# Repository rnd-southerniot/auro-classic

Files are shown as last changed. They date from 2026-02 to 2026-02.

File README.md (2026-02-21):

# Airborne Classic (Aurbotstem Academy)

XRP-style robot car firmware stack for STEM learning, currently focused on USB serial bring-up and deterministic RP2040 control.

## Current Status (February 21, 2026)
- Gate P1-0: PASS (MicroPython deploy, boot telemetry, `ping` ack, DISARMED-by-default).
- Gate P1-1: PASS (IRQ encoder counting validated with wheel-direction tests).
- PicoSDK track: active and validated (build/flash/smoke PASS, PIO encoder telemetry integrated).

## Repository Layout
- `firmware_mpy/`: MicroPython firmware (`main.py`, `lib/hw.py`, `config.json`).
- `firmware_sdk/`: PicoSDK firmware with NDJSON loop and PIO encoder sampler.
- `protocol/`: NDJSON protocol spec + JSON schema.
- `tools/`: host utilities (`mpy_sync.sh`, CAD bbox extraction).
- `cad/`: chassis/wheel 3MF artifacts and extracted metadata.
- `docs/`: phase status and project notes.
- `skills/`: reusable Codex skills for this repo.
- `MEMORY.md`: persistent decisions and validated environment facts.

## Quick Start: MicroPython Path
```bash
python3 -m pip install --upgrade mpremote
./tools/mpy_sync.sh
```
Expected behavior: boot telemetry in `DISARMED` mode, then `{"type":"ack","id":"1","ok":true}` for `ping`.

## Quick Start: PicoSDK Path
Install local dependencies (one-time):
```bash
git clone --depth 1 https://github.com/raspberrypi/pico-sdk.git third_party/pico-sdk
git -C third_party/pico-sdk submodule update --init --recursive
curl -fL -o /tmp/arm-gnu-toolchain.tar.xz https://developer.arm.com/-/media/Files/downloads/gnu/15.2.rel1/binrel/arm-gnu-toolchain-15.2.rel1-darwin-arm64-arm-none-eabi.tar.xz
tar -xf /tmp/arm-gnu-toolchain.tar.xz -C third_party
```

Then build:
```bash
export PICO_SDK_PATH="$PWD/third_party/pico-sdk"
export PICO_TOOLCHAIN_PATH="$PWD/third_party/arm-gnu-toolchain-15.2.rel1-darwin-arm64-arm-none-eabi/bin"
cmake -S firmware_sdk -B firmware_sdk/build-pico-arm -G Ninja
cmake --build firmware_sdk/build-pico-arm -j
```
Flash UF2: copy `firmware_sdk/build-pico-arm/airborne_classic_fw.uf2` to `RPI-RP2`.

## Source of Truth
- Hardware: `HARDWARE_MAP.md`
- Serial protocol: `protocol/ndjson_v1.md`
- Latest phase evidence: `docs/PHASE1_STATUS.md`

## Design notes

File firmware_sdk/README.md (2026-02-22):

# firmware_sdk

PicoSDK production firmware for Airborne Classic.

## Scope
Current implementation provides:
- USB NDJSON command/telemetry loop in `src/main.c`
- PIO-based quadrature sampling (`src/quadrature_sample.pio`)
- encoder count telemetry fields (`enc_l`, `enc_r`)

## Prerequisites
- Pico SDK checkout
- Arm GNU toolchain with `arm-none-eabi-*`
- CMake + Ninja

Tested local setup:
- `PICO_SDK_PATH=$PWD/third_party/pico-sdk`
- `PICO_TOOLCHAIN_PATH=$PWD/third_party/arm-gnu-toolchain-15.2.rel1-darwin-arm64-arm-none-eabi/bin`

## Install Local Dependencies (one-time)
```bash
git clone --depth 1 https://github.com/raspberrypi/pico-sdk.git third_party/pico-sdk
git -C third_party/pico-sdk submodule update --init --recursive
curl -fL -o /tmp/arm-gnu-toolchain.tar.xz https://developer.arm.com/-/media/Files/downloads/gnu/15.2.rel1/binrel/arm-gnu-toolchain-15.2.rel1-darwin-arm64-arm-none-eabi.tar.xz
tar -xf /tmp/arm-gnu-toolchain.tar.xz -C third_party
```

## Build
```bash
cmake -S firmware_sdk -B firmware_sdk/build-pico-arm -G Ninja
cmake --build firmware_sdk/build-pico-arm -j
```

## Flash
1. Reboot to BOOTSEL (`picotool reboot -u -f`) or hold BOOTSEL while plugging USB.
2. Copy `firmware_sdk/build-pico-arm/airborne_classic_fw.uf2` to `RPI-RP2`.

## Protocol Coverage
Implemented command subset:
- `ping`, `version`, `arm`, `disarm`, `set_pwm`, `set_rpm`, `cal_encoders`, `cal_imu`, `stop`

`set_rpm` currently maps target RPM values to open-loop PWM using `OPEN_LOOP_MAX_ABS_RPM` in `src/main.c`.
`cal_encoders` resets encoder counts and RPM integrators; `cal_imu` currently returns a noop ack.

Telemetry:
- `mode`, `armed`, `pwm_l`, `pwm_r`, `enc_l`, `enc_r`, `rpm_l`, `rpm_r`, `yaw`, `fault`
- `rpm_*` is estimated from encoder deltas each telemetry interval.
- `COUNTS_PER_WHEEL_REV_L/R` in `src/main.c` are currently calibrated to `582/583` from Feb 22, 2026 bench trials.

## Notes
- Pin mapping remains anchored in `HARDWARE_MAP.md`.
- Protocol compatibility target remains `protocol/ndjson_v1.md`.
- Encoder sign is normalized in telemetry using `ENC_L_SIGN` / `ENC_R_SIGN` in `src/main.c`.

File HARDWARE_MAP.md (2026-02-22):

# Airborne Classic — HARDWARE_MAP (source of truth)

## Chassis / kinematics (LOCKED TO PRINTED CAD)

Source: 3MF CAD files in `cad/`.

- Wheel diameter (CAD bbox): **~54.875 mm** (treat as 55 mm)
- Wheel thickness (CAD bbox): **~9.125 mm**
- Track width (CAD assembly, wheel-center to wheel-center): **~155.0 mm** *(computed)*
- Wheelbase (measured): **62 mm** (drive axle center → caster contact center)

> Current CAD-derived frame overall extents (PCA-aligned bbox):
> - Length/width extents (two largest): ~223.78 mm and ~222.30 mm
> - Height extent (smallest): ~38.50 mm
>
> TODO (still needs extraction of axle center positions):
> - Track width (wheel-center to wheel-center)
> - Wheelbase (axle-center to axle-center)
> - Encoder mounting geometry

## Controller: Cytron Maker Pi RP2040 (Pico)

### Motor driver pins (locked)
- M1A = GP8
- M1B = GP9
- M2A = GP10
- M2B = GP11

Truth table:
- 00 brake
- 10 forward
- 01 backward
- 11 coast (Hi-Z)

PWM frequency target: ~20 kHz

### Onboard peripherals
- WS2812 RGB: GP18
- Buttons: GP20, GP21
- Buzzer: GP22
- Servo signals: GP12–GP15

## Encoders (quadrature, locked approach)

### Pin assignment (chosen)
- Left: ENC_L_A = GP2, ENC_L_B = GP3
- Right: ENC_R_A = GP4, ENC_R_B = GP5

### Decoder strategy
- MicroPython bring-up: IRQ-based counting (low speed)
- PicoSDK production: PIO-based sampling + CPU transition decode
- Telemetry sign convention: forward normalized positive on both channels (`ENC_L_SIGN=1`, `ENC_R_SIGN=-1`)

### Calibration
- counts-per-wheel-rev (measured February 22, 2026; 3 manual 1-rev trials each):
  - left trials: 576, 586, 585 -> average 582.33 -> use **582**
  - right trials: 575, 591, 584 -> average 583.33 -> use **583**
- wheel diameter: locked to CAD (~55 mm)

## IMU: ICM-20948

### Bus (chosen)
- I2C1: SDA=GP6, SCL=GP7

> TODO: confirm ICM-20948 I2C address on your breakout and whether AD0 is strapped.

## Power
- TBD (battery type/voltage for car)

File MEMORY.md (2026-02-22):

# Project Memory

## Stable Decisions
- Use gate-based development with stop-on-FAIL and transcript evidence.
- Treat `HARDWARE_MAP.md` as hardware source of truth.
- Treat `protocol/ndjson_v1.md` as wire contract; staged subset implementation is allowed by gate.

## Validated Hardware/Firmware Facts
- Board: Cytron Maker Pi RP2040.
- Encoder pins: left GP2/GP3, right GP4/GP5.
- Motor pins: GP8-GP11.
- I2C bus for IMU mapping: `I2C1` on GP6/GP7.
- MicroPython runtime requires stdout flush guard (`sys.stdout.flush` may be absent).

## Validated Build/Flash Facts
- PicoSDK build works with local vendored toolchain + SDK under `third_party/`.
- Working build output path: `firmware_sdk/build-pico-arm/airborne_classic_fw.uf2`.
- Reliable BOOTSEL command flow:
  - `picotool reboot -u -f`
  - copy UF2 to `RPI-RP2`.

## Encoder Sign Convention
- Telemetry is normalized so forward is positive for both channels.
- Configured in `firmware_sdk/src/main.c` with:
  - `ENC_L_SIGN = 1`
  - `ENC_R_SIGN = -1`

## Encoder Calibration Baseline
- Date: February 22, 2026.
- Left counts/rev trials: 576, 586, 585 -> average 582.33 -> configured 582.
- Right counts/rev trials: 575, 591, 584 -> average 583.33 -> configured 583.

## Current Priorities
1. Replace open-loop `set_rpm` mapping with closed-loop RPM control.
2. Replace `cal_imu` noop with hardware-backed IMU calibration flow.
3. Add persistent calibration command flow to write/read runtime calibration values.

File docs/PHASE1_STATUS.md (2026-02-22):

# Phase 1 Status (As of February 22, 2026)

## Gate Results
- P1-0: PASS
- P1-1: PASS
- PicoSDK smoke gate: PASS

## Verified Behaviors
- MicroPython path:
  - deploy via `./tools/mpy_sync.sh`
  - boot telemetry in `DISARMED`
  - `ping` ack success
  - encoder IRQ counting with direction-dependent deltas
- PicoSDK path:
  - deterministic build with local SDK/toolchain
  - UF2 flash to RP2040
  - NDJSON command loop acks for `ping/version/arm/disarm/set_pwm/set_rpm/cal_encoders/cal_imu/stop`
  - PIO-derived encoder telemetry (`enc_l`, `enc_r`)

## Build Environment Used
- `PICO_SDK_PATH=/Users/robotics/airborne-classic/third_party/pico-sdk`
- `PICO_TOOLCHAIN_PATH=/Users/robotics/airborne-classic/third_party/arm-gnu-toolchain-15.2.rel1-darwin-arm64-arm-none-eabi/bin`
- Board serial: `/dev/cu.usbmodem211301`

## Known Gaps
- IMU calibration is currently a protocol-compatible noop ack (sensor calibration flow not implemented).
- Closed-loop RPM control is not implemented yet (`set_rpm` is open-loop mapping).

## Calibration Snapshot (February 22, 2026)
- Left wheel counts/rev trials: `576`, `586`, `585` -> average `582.33` -> configured `582`.
- Right wheel counts/rev trials: `575`, `591`, `584` -> average `583.33` -> configured `583`.

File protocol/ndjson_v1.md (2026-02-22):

# NDJSON Serial Protocol v1 (Airborne Classic)

Transport: USB CDC serial
Encoding: newline-delimited JSON (one JSON object per line)

## Commands (Hub → Controller)

All commands include:
- `type: "cmd"`
- `id`: string UUID
- `ts`: epoch milliseconds
- `cmd`: command name

### Arm/disarm
```json
{"type":"cmd","id":"uuid","ts":0,"cmd":"arm"}
{"type":"cmd","id":"uuid","ts":0,"cmd":"disarm"}
```

### Motor control
Open loop PWM (normalized -1..1):
```json
{"type":"cmd","id":"uuid","ts":0,"cmd":"set_pwm","left":0.2,"right":0.2}
```

RPM command:
```json
{"type":"cmd","id":"uuid","ts":0,"cmd":"set_rpm","left":120,"right":120}
```
Current firmware subsets map RPM targets to open-loop PWM; closed-loop control is a later phase.

Emergency stop:
```json
{"type":"cmd","id":"uuid","ts":0,"cmd":"stop"}
```

### Calibration
```json
{"type":"cmd","id":"uuid","ts":0,"cmd":"cal_imu"}
{"type":"cmd","id":"uuid","ts":0,"cmd":"cal_encoders"}
```

### Introspection
```json
{"type":"cmd","id":"uuid","ts":0,"cmd":"ping"}
{"type":"cmd","id":"uuid","ts":0,"cmd":"i2c_scan"}
{"type":"cmd","id":"uuid","ts":0,"cmd":"version"}
```

### Logging
Default is **NDJSON only**. Human logs can be enabled for debugging.

```json
{"type":"cmd","id":"uuid","ts":0,"cmd":"set_log","on":true}
{"type":"cmd","id":"uuid","ts":0,"cmd":"set_log","on":false}
```

Human log lines are prefixed with `# ` so parsers can ignore them.

## Telemetry (Controller → Hub)

Telemetry at 10–50 Hz depending mode.

```json
{
  "type":"tele",
  "ts":0,
  "mode":"DISARMED|ARMED|TELEOP|AUTO|FAULT",
  "armed":false,
  "pwm_l":0.0,
  "pwm_r":0.0,
  "enc_l":0,
  "enc_r":0,
  "rpm_l":0.0,
  "rpm_r":0.0,
  "yaw":0.0,
  "fault":null
}
```

## Acks (Controller → Hub)

```json
{"type":"ack","id":"uuid","ok":true}
```

Error:
```json
{"type":"ack","id":"uuid","ok":false,"error":{"code":"bad_cmd","message":"..."}}
```

## Implementation Status (February 22, 2026)

Protocol v1 is the contract; firmware tracks it in staged subsets.

- MicroPython (`firmware_mpy/main.py`) currently implements:
  - `ping`, `set_log`, `version`, `i2c_scan`, `arm`, `disarm`, `stop`, `set_pwm`, `set_rpm` (open-loop mapping), `cal_encoders`, `cal_imu` (noop ack)
- PicoSDK (`firmware_sdk/src/main.c`) currently implements:
  - `ping`, `version`, `arm`, `disarm`, `stop`, `set_pwm`, `set_rpm` (open-loop mapping), `cal_encoders`, `cal_imu` (noop ack)
- Deferred in both tracks (planned later gates):
  - hardware-backed IMU calibration flow

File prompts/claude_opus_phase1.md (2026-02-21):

# Claude Opus — Airborne Classic (Phase 1) Master Prompt

Use this prompt with Claude Opus (4.x). If your tooling asks for a model name, use your provider's Opus alias.

## Role
You are a senior robotics+curriculum engineer. Produce a gate-based plan and code changes for Phase 1 (USB-only):
- MicroPython auto-run bring-up
- PicoSDK production firmware (PIO encoders)
- local-only learning hub for a teacher Mac

## Inputs
- Hardware map: `HARDWARE_MAP.md`
- NDJSON protocol: `protocol/ndjson_v1.md`
- Maker Pi RP2040 motor pins: GP8–GP11 (truth table)
- Encoders: quadrature A/B
- IMU: ICM-20948 via I2C
- Kinematics locked to printed CAD:
  - wheel dia ~55mm
  - track width ~155mm
  - wheelbase 62mm

## Output requirements
1) Provide Gate P1-0..P1-3 checklists.
2) For each gate, list tests and expected logs.
3) Provide minimal code diffs for the MicroPython skeleton first.
4) Do not start PicoSDK until MP gates pass.
5) Provide a student-facing mini-lab outline for Gate P1-2 and P1-3.

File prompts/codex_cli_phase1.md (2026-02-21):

# Codex CLI — Airborne Classic (Phase 1) Master Prompt

Paste into codex CLI.

## Mission
Build Phase 1 (USB-only) for **Airborne Classic**: MicroPython bring-up track (auto-run) + PicoSDK production track (PIO encoders) + local-only teacher learning hub.

## Non-negotiables
- Gate-based development. Stop on FAIL.
- Source-of-truth hardware in `HARDWARE_MAP.md`.
- NDJSON protocol v1 in `protocol/ndjson_v1.md`.

## Repository
Root: `airborne-classic/`

## Gate P1-0 (deliver now)
1) Confirm `HARDWARE_MAP.md` exists and is consistent.
2) Implement MicroPython auto-run skeleton:
   - `firmware_mpy/main.py`
   - `firmware_mpy/lib/hw.py`
   - `firmware_mpy/config.json`
   - `tools/mpy_sync.sh`
3) Provide a tiny verification transcript:
   - `mpy_sync.sh`
   - `echo '{"type":"cmd","id":"1","ts":0,"cmd":"ping"}' | <serial>` (or via mpremote repl)

## Gate P1-1 (next)
- Expand MicroPython to include encoder IRQ counting for slow speed.

## PicoSDK track (do not start until MP gates pass)
- Create `firmware_sdk/` skeleton with:
  - quadrature PIO plan
  - build instructions

## Output format
- Print PASS/FAIL for Gate P1-0 with evidence.
- If FAIL, provide debug checklist.

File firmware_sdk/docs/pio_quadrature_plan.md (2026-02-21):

# Quadrature PIO Plan

## Goal
Implement deterministic encoder counting on RP2040 PIO for Airborne Classic production firmware.

## Hardware Inputs
From `HARDWARE_MAP.md`:
- Left encoder: `ENC_L_A=GP2`, `ENC_L_B=GP3`
- Right encoder: `ENC_R_A=GP4`, `ENC_R_B=GP5`

## Architecture
- Use one PIO state machine per wheel encoder.
- Each state machine samples A/B, tracks 2-bit state transitions, and emits signed step deltas.
- Core loop aggregates deltas into 32-bit counts (`enc_l`, `enc_r`).

## Data Path
1. PIO captures edge transitions with fixed timing.
2. IRQ or FIFO polling transfers deltas to CPU.
3. Control task updates counts and computes low-rate RPM.
4. Telemetry publishes NDJSON-compatible fields (`enc_l`, `enc_r`, `rpm_l`, `rpm_r`).

## Failure Handling
- Invalid transitions (`00->11`, `01->10`) are counted as noise events.
- FIFO overflow increments an overflow counter and raises a soft fault.
- Encoder disconnect detection: no transitions for a configurable timeout while PWM is non-zero.

## Milestones
1. PIO state machine stub compiles and streams raw A/B states.
2. Signed delta decoding validated against hand rotation.
3. Count accumulation + overflow counters integrated.
4. Telemetry export aligned with `protocol/ndjson_v1.md`.

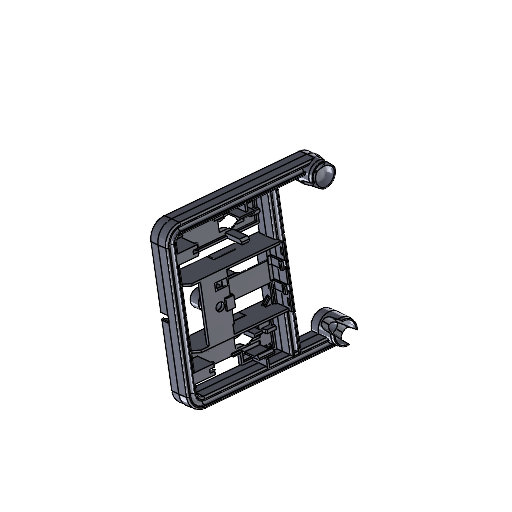
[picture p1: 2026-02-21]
cad/extracted/frame/Metadata/thumbnail.png

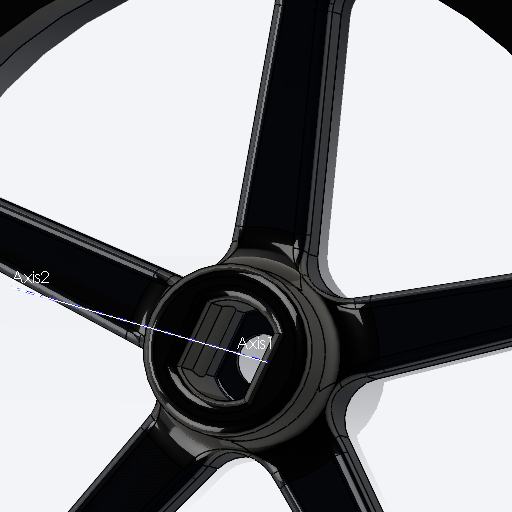
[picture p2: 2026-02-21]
cad/extracted/wheel/Metadata/thumbnail.png

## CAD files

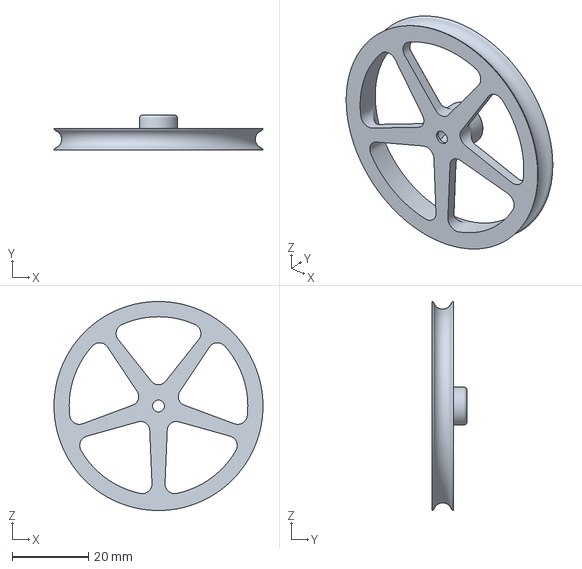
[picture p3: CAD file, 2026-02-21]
cad/wheel-fixed-bore.3mf
54.9 x 9.13 x 54.9 mm

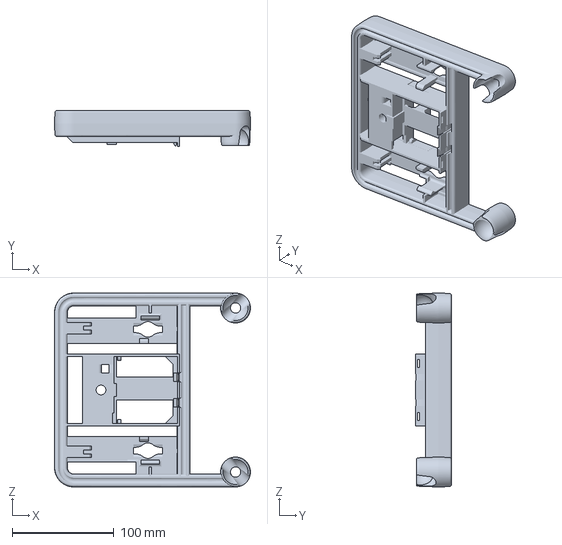
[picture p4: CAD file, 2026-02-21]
cad/single-part-frame-v13.3mf
192.5 x 35.2 x 190.5 mm

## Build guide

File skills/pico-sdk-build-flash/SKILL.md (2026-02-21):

---
name: pico-sdk-build-flash
description: Build, flash, and smoke-test Airborne Classic PicoSDK firmware on RP2040 using reproducible local paths and UF2 workflows. Use when configuring toolchain paths, running CMake/Ninja builds, rebooting to BOOTSEL, copying UF2 images, and verifying NDJSON telemetry/ack behavior after flash.
---

# Pico SDK Build Flash

## Use Deterministic Build Paths
1. Prefer repository-local toolchain and SDK paths from `references/build-paths.md`.
2. Configure with Ninja and an explicit build directory (`firmware_sdk/build-pico-arm`).
3. Re-run configure when CMake cache uses a different generator.

## Build Then Flash
1. Run `scripts/build_sdk.sh` first.
2. Run `scripts/flash_uf2.sh` with the UF2 path.
3. If copy fails on first attempt, retry once after mount confirms writable BOOTSEL volume.

## Smoke-Test Immediately
- Send `ping` and `version` commands and verify acks.
- Confirm telemetry stream appears without parse errors.
- Check encoder fields are present (`enc_l`, `enc_r`).

## Resources
- `references/build-paths.md`: canonical env/path values and fallback notes.
- `scripts/build_sdk.sh`: deterministic build wrapper.
- `scripts/flash_uf2.sh`: BOOTSEL flash helper.

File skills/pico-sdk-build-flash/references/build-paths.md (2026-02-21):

# Build Paths

## Preferred Local Paths
- `PICO_SDK_PATH=$REPO/third_party/pico-sdk`
- `PICO_TOOLCHAIN_PATH=$REPO/third_party/arm-gnu-toolchain-15.2.rel1-darwin-arm64-arm-none-eabi/bin`

## Configure + Build
```bash
PICO_SDK_PATH="$PWD/third_party/pico-sdk" \
PICO_TOOLCHAIN_PATH="$PWD/third_party/arm-gnu-toolchain-15.2.rel1-darwin-arm64-arm-none-eabi/bin" \
cmake -S firmware_sdk -B firmware_sdk/build-pico-arm -G Ninja

PICO_SDK_PATH="$PWD/third_party/pico-sdk" \
PICO_TOOLCHAIN_PATH="$PWD/third_party/arm-gnu-toolchain-15.2.rel1-darwin-arm64-arm-none-eabi/bin" \
cmake --build firmware_sdk/build-pico-arm -j
```

## Flash
- Reboot to BOOTSEL: `picotool reboot -u -f`
- Copy UF2 to `RPI-RP2`.

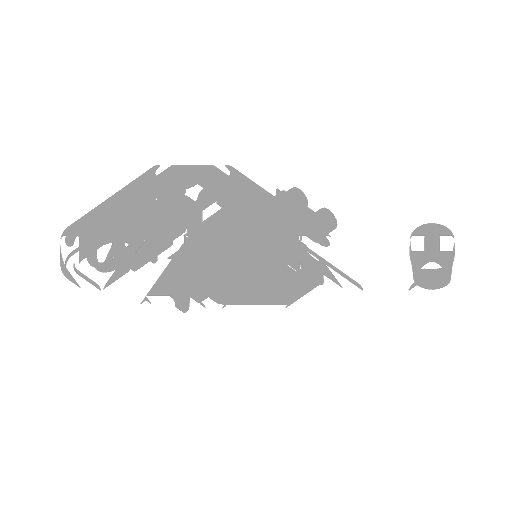
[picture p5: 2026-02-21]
cad/assembly2/extracted/Metadata/plate_no_light_1.png

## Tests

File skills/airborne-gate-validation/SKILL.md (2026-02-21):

---
name: airborne-gate-validation
description: Run gate-based validation for Airborne Classic RP2040 firmware with stop-on-fail behavior and transcript evidence. Use when verifying MicroPython or PicoSDK firmware gates, capturing serial ack/telemetry output, checking disarm/arm safety flow, validating encoder direction deltas, or preparing PASS/FAIL gate reports.
---

# Airborne Gate Validation

## Execute Gate Workflow
1. Load the checklist in `references/gate-checklist.md` and select the target track (`firmware_mpy` or `firmware_sdk`).
2. Start with non-motion checks first: boot telemetry, `ping`, `version`, and disarm safety.
3. Stop immediately on first failure and produce a focused debug checklist.
4. Only continue motion-based checks after non-motion checks pass.

## Capture Evidence
- Use `scripts/serial_capture.py` to collect line-by-line serial evidence.
- Always include:
  - commands sent,
  - ack lines,
  - at least one telemetry sample around each command.
- For encoder checks, report `delta_l` and `delta_r` over a fixed window.

## Report Format
- Print one gate status line: `Gate <name>: PASS|FAIL`.
- If PASS: include key evidence snippets and next gate recommendation.
- If FAIL: include exact failing step, raw error line, and immediate debug actions.

## Resources
- `references/gate-checklist.md`: execution order and acceptance criteria.
- `scripts/serial_capture.py`: repeatable capture utility for NDJSON sessions.

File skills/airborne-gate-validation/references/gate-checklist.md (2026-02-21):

# Gate Checklist

## Preflight
- Confirm board serial device (for example `/dev/cu.usbmodem211301`).
- Confirm firmware image to validate (`firmware_mpy` or `firmware_sdk`).
- Keep robot disarmed unless a test step explicitly requires `arm`.

## Baseline Checks
1. Boot telemetry appears and includes `mode` + `armed`.
2. `ping` command returns `{"type":"ack","ok":true}`.
3. `version` returns firmware identity.
4. Safety sequence (`disarm -> arm -> stop -> disarm`) returns all acks.

## Encoder Checks
1. Idle window: counts stable.
2. Left forward/backward windows: sign flips, right channel remains stable.
3. Right forward/backward windows: sign flips, left channel remains stable.
4. Document observed sign convention and whether normalization is applied.

## Failure Handling
- Stop on first failure.
- Capture raw line showing the failure.
- Suggest only the minimal corrective action before retry.

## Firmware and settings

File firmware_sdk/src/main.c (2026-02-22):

#include <stdbool.h>
#include <stdint.h>
#include <stdio.h>
#include <stdlib.h>
#include <string.h>
#include <math.h>

#include "hardware/gpio.h"
#include "hardware/pio.h"
#include "hardware/pwm.h"
#include "pico/stdlib.h"
#include "quadrature_sample.pio.h"

#define LINE_BUF_SIZE 256
#define ENC_L_PIN_BASE 2u
#define ENC_R_PIN_BASE 4u
#define ENCODER_SAMPLE_HZ 2000.0f
#define MOTOR_L_A_PIN 8u
#define MOTOR_L_B_PIN 9u
#define MOTOR_R_A_PIN 10u
#define MOTOR_R_B_PIN 11u
#define MOTOR_PWM_HZ 20000u
#define MOTOR_PWM_WRAP 6249u
#define ENC_L_SIGN 1
#define ENC_R_SIGN -1
// Calibrated from three 1-rev hand-turn trials (Feb 22, 2026):
// left: 576, 586, 585 -> 582.33 ; right: 575, 591, 584 -> 583.33
#define COUNTS_PER_WHEEL_REV_L 582.0f
#define COUNTS_PER_WHEEL_REV_R 583.0f
// Open-loop RPM command range mapped to PWM [-1, 1].
#define OPEN_LOOP_MAX_ABS_RPM 200.0f

typedef struct {
    bool armed;
    float pwm_l;
    float pwm_r;
    int32_t enc_l;
    int32_t enc_r;
    float rpm_l;
    float rpm_r;
} robot_state_t;

typedef struct {
    PIO pio;
    uint sm;
    uint pin_base;
    uint8_t prev_state;
    int32_t count;
} encoder_reader_t;

static uint32_t now_ms(void) {
    return to_ms_since_boot(get_absolute_time());
}

static void emit_tele(const robot_state_t *s) {
    printf(
        "{\"type\":\"tele\",\"ts\":%lu,\"mode\":\"%s\",\"armed\":%s,"
        "\"pwm_l\":%.3f,\"pwm_r\":%.3f,\"enc_l\":%ld,\"enc_r\":%ld,"
        "\"rpm_l\":%.3f,\"rpm_r\":%.3f,\"yaw\":0.0,\"fault\":null}\n",
        (unsigned long)now_ms(),
        s->armed ? "ARMED" : "DISARMED",
        s->armed ? "true" : "false",
        s->pwm_l,
        s->pwm_r,
        (long)s->enc_l,
        (long)s->enc_r,
        s->rpm_l,
        s->rpm_r
    );
}

static void emit_ack_ok(const char *id, const char *data_json_or_null) {
    if (data_json_or_null) {
        printf("{\"type\":\"ack\",\"id\":\"%s\",\"ok\":true,\"data\":%s}\n", id, data_json_or_null);
    } else {
        printf("{\"type\":\"ack\",\"id\":\"%s\",\"ok\":true}\n", id);
    }
}

static void emit_ack_err(const char *id, const char *code, const char *message) {
    printf(
        "{\"type\":\"ack\",\"id\":\"%s\",\"ok\":false,"
        "\"error\":{\"code\":\"%s\",\"message\":\"%s\"}}\n",
        id,
        code,
        message
    );
}

static bool extract_string_field(const char *line, const char *field, char *out, size_t out_size) {
    const char *p = strstr(line, field);
    const char *start;
    const char *end;
    size_t n;

    if (!p || out_size == 0) {
        return false;
    }
    p = strchr(p, ':');
    if (!p) {
        return false;
    }
    start = strchr(p, '"');
    if (!start) {
        return false;
    }
    start++;
    end = strchr(start, '"');
    if (!end) {
        return false;
    }
    n = (size_t)(end - start);
    if (n >= out_size) {
        n = out_size - 1;
    }
    memcpy(out, start, n);
    out[n] = '\0';
    return true;
}

static bool extract_number_field(const char *line, const char *field, float *value_out) {
    const char *p = strstr(line, field);
    char *endptr;
    float v;
    if (!p) {
        return false;
    }
    p = strchr(p, ':');
    if (!p) {
        return false;
    }
    p++;
    v = strtof(p, &endptr);
    if (endptr == p) {
        return false;
    }
    *value_out = v;
    return true;
}

static int quad_delta(uint8_t prev, uint8_t cur) {
    if (prev == cur) {
        return 0;
    }
    if (
        (prev == 0 && cur == 1) ||
        (prev == 1 && cur == 3) ||
        (prev == 3 && cur == 2) ||
        (prev == 2 && cur == 0)
    ) {
        return 1;
    }
    if (
        (prev == 0 && cur == 2) ||
        (prev == 2 && cur == 3) ||
        (prev == 3 && cur == 1) ||
        (prev == 1 && cur == 0)
    ) {
        return -1;
    }
    return 0;
}

static uint8_t read_encoder_state_from_gpio(uint pin_base) {
    uint8_t a = (uint8_t)gpio_get(pin_base);
    uint8_t b = (uint8_t)gpio_get(pin_base + 1u);
    return (uint8_t)((a << 1u) | b);
}

static void encoder_reader_init(encoder_reader_t *enc, PIO pio, uint sm, uint pin_base, uint offset) {
    pio_sm_config cfg = quadrature_sample_program_get_default_config(offset);

    enc->pio = pio;
    enc->sm = sm;
    enc->pin_base = pin_base;
    enc->count = 0;

    pio_gpio_init(pio, pin_base);
    pio_gpio_init(pio, pin_base + 1u);
    gpio_pull_up(pin_base);
    gpio_pull_up(pin_base + 1u);
    pio_sm_set_consecutive_pindirs(pio, sm, pin_base, 2, false);

    sm_config_set_in_pins(&cfg, pin_base);
    sm_config_set_clkdiv(&cfg, 125000000.0f / ENCODER_SAMPLE_HZ);

    pio_sm_init(pio, sm, offset, &cfg);
    enc->prev_state = read_encoder_state_from_gpio(pin_base);
    pio_sm_set_enabled(pio, sm, true);
}

static void encoder_reader_poll(encoder_reader_t *enc) {
    while (!pio_sm_is_rx_fifo_empty(enc->pio, enc->sm)) {
        uint32_t raw = pio_sm_get(enc->pio, enc->sm);
        uint8_t cur = (uint8_t)((raw >> 30u) & 0x3u);
        enc->count += quad_delta(enc->prev_state, cur);
        enc->prev_state = cur;
    }
}

static float counts_to_rpm(int32_t delta_counts, uint32_t delta_ms, float counts_per_rev) {
    if (delta_ms == 0u || counts_per_rev <= 0.0f) {
        return 0.0f;
    }
    return ((float)delta_counts * 60000.0f) / (counts_per_rev * (float)delta_ms);
}

static float clamp_unit(float v) {
    if (v > 1.0f) {
        return 1.0f;
    }
    if (v < -1.0f) {
        return -1.0f;
    }
    return v;
}

static float rpm_to_pwm(float rpm) {
    if (OPEN_LOOP_MAX_ABS_RPM <= 0.0f) {
        return 0.0f;
    }
    return clamp_unit(rpm / OPEN_LOOP_MAX_ABS_RPM);
}

static uint16_t unit_to_pwm_level(float v) {
    float mag = fabsf(clamp_unit(v));
    return (uint16_t)(mag * (float)MOTOR_PWM_WRAP);
}

static void drive_hbridge(uint pin_a, uint pin_b, float v) {
    uint16_t level = unit_to_pwm_level(v);
    // Cytron truth table:
    // 00 brake
    // 10 forward
    // 01 backward
    // 11 coast (Hi-Z)
    if (v > 0.0f) {
        pwm_set_gpio_level(pin_a, level);
        pwm_set_gpio_level(pin_b, 0u);
    } else if (v < 0.0f) {
        pwm_set_gpio_level(pin_a, 0u);
        pwm_set_gpio_level(pin_b, level);
    } else {
        pwm_set_gpio_level(pin_a, 0u);
        pwm_set_gpio_level(pin_b, 0u);
    }
}

static void apply_motor_outputs(const robot_state_t *s) {
    float left = s->armed ? clamp_unit(s->pwm_l) : 0.0f;
    float right = s->armed ? clamp_unit(s->pwm_r) : 0.0f;
    drive_hbridge(MOTOR_L_A_PIN, MOTOR_L_B_PIN, left);
    drive_hbridge(MOTOR_R_A_PIN, MOTOR_R_B_PIN, right);
}

static void motor_pwm_init(void) {
    uint pins[] = {MOTOR_L_A_PIN, MOTOR_L_B_PIN, MOTOR_R_A_PIN, MOTOR_R_B_PIN};
    for (size_t i = 0; i < sizeof(pins) / sizeof(pins[0]); i++) {
        gpio_set_function(pins[i], GPIO_FUNC_PWM);
    }

    uint slice_l = pwm_gpio_to_slice_num(MOTOR_L_A_PIN);
    uint slice_r = pwm_gpio_to_slice_num(MOTOR_R_A_PIN);
    pwm_set_wrap(slice_l, MOTOR_PWM_WRAP);
    pwm_set_clkdiv(slice_l, 1.0f);
    pwm_set_enabled(slice_l, true);

    pwm_set_wrap(slice_r, MOTOR_PWM_WRAP);
    pwm_set_clkdiv(slice_r, 1.0f);
    pwm_set_enabled(slice_r, true);

    pwm_set_gpio_level(MOTOR_L_A_PIN, 0u);
    pwm_set_gpio_level(MOTOR_L_B_PIN, 0u);
    pwm_set_gpio_level(MOTOR_R_A_PIN, 0u);
    pwm_set_gpio_level(MOTOR_R_B_PIN, 0u);
}

static void handle_line(
    const char *line,
    robot_state_t *s,
    encoder_reader_t *enc_l_reader,
    encoder_reader_t *enc_r_reader,
    int32_t *last_enc_l,
    int32_t *last_enc_r,
    uint32_t *last_tele_ts
) {
    char id[64];
    float left = 0.0f;
    float right = 0.0f;

    if (!extract_string_field(line, "\"id\"", id, sizeof(id))) {
        strncpy(id, "?", sizeof(id));
        id[sizeof(id) - 1] = '\0';
    }

    if (!strstr(line, "\"type\":\"cmd\"")) {
        emit_ack_err(id, "bad_type", "expected cmd");
        return;
    }

    if (strstr(line, "\"cmd\":\"ping\"")) {
        emit_ack_ok(id, NULL);
        return;
    }
    if (strstr(line, "\"cmd\":\"version\"")) {
        emit_ack_ok(id, "{\"fw\":\"sdk-v0\",\"robot\":\"airborne-classic\"}");
        return;
    }
    if (strstr(line, "\"cmd\":\"arm\"")) {
        s->armed = true;
        emit_ack_ok(id, NULL);
        return;
    }
    if (strstr(line, "\"cmd\":\"disarm\"")) {
        s->armed = false;
        s->pwm_l = 0.0f;
        s->pwm_r = 0.0f;
        emit_ack_ok(id, NULL);
        return;
    }
    if (strstr(line, "\"cmd\":\"stop\"")) {
        s->pwm_l = 0.0f;
        s->pwm_r = 0.0f;
        emit_ack_ok(id, NULL);
        return;
    }
    if (strstr(line, "\"cmd\":\"set_pwm\"")) {
        if (!extract_number_field(line, "\"left\"", &left) || !extract_number_field(line, "\"right\"", &right)) {
            emit_ack_err(id, "bad_args", "expected left/right numbers");
            return;
        }
        if (!s->armed) {
            s->pwm_l = 0.0f;
            s->pwm_r = 0.0f;
        } else {
            s->pwm_l = clamp_unit(left);
            s->pwm_r = clamp_unit(right);
        }
        emit_ack_ok(id, NULL);
        return;
    }
    if (strstr(line, "\"cmd\":\"set_rpm\"")) {
        if (!extract_number_field(line, "\"left\"", &left) || !extract_number_field(line, "\"right\"", &right)) {
            emit_ack_err(id, "bad_args", "expected left/right numbers");
            return;
        }
        if (!s->armed) {
            s->pwm_l = 0.0f;
            s->pwm_r = 0.0f;
        } else {
            s->pwm_l = rpm_to_pwm(left);
            s->pwm_r = rpm_to_pwm(right);
        }
        emit_ack_ok(id, NULL);
        return;
    }
    if (strstr(line, "\"cmd\":\"cal_encoders\"")) {
        enc_l_reader->count = 0;
        enc_r_reader->count = 0;
        s->enc_l = 0;
        s->enc_r = 0;
        s->rpm_l = 0.0f;
        s->rpm_r = 0.0f;
        *last_enc_l = 0;
        *last_enc_r = 0;
        *last_tele_ts = now_ms();
        emit_ack_ok(id, NULL);
        return;
    }
    if (strstr(line, "\"cmd\":\"cal_imu\"")) {
        emit_ack_ok(id, "{\"status\":\"noop\"}");
        return;
    }

    emit_ack_err(id, "bad_cmd", "unknown cmd");
}

int main(void) {
    absolute_time_t next_tele;
    uint offset;
    uint sm_l;
    uint sm_r;
    uint32_t last_tele_ts;
    int32_t last_enc_l;
    int32_t last_enc_r;
    encoder_reader_t enc_l_reader;
    encoder_reader_t enc_r_reader;
    char line[LINE_BUF_SIZE];
    size_t line_len = 0;
    robot_state_t state = {
        .armed = false,
        .pwm_l = 0.0f,
        .pwm_r = 0.0f,
        .enc_l = 0,
        .enc_r = 0,
        .rpm_l = 0.0f,
        .rpm_r = 0.0f
    };

    stdio_init_all();
    sleep_ms(1000);
    motor_pwm_init();

    offset = pio_add_program(pio0, &quadrature_sample_program);
    sm_l = pio_claim_unused_sm(pio0, true);
    sm_r = pio_claim_unused_sm(pio0, true);
    encoder_reader_init(&enc_l_reader, pio0, sm_l, ENC_L_PIN_BASE, offset);
    encoder_reader_init(&enc_r_reader, pio0, sm_r, ENC_R_PIN_BASE, offset);

    last_tele_ts = now_ms();
    last_enc_l = 0;
    last_enc_r = 0;

    emit_tele(&state);
    next_tele = make_timeout_time_ms(100);

    while (true) {
        int c = getchar_timeout_us(0);
        if (c != PICO_ERROR_TIMEOUT) {
            if (c == '\r' || c == '\n') {
                line[line_len] = '\0';
                if (line_len > 0) {
                    handle_line(
                        line,
                        &state,
                        &enc_l_reader,
                        &enc_r_reader,
                        &last_enc_l,
                        &last_enc_r,
                        &last_tele_ts
                    );
                }
                line_len = 0;
            } else if (line_len + 1 < LINE_BUF_SIZE) {
                line[line_len++] = (char)c;
            } else {
                line_len = 0;
            }
        }

        encoder_reader_poll(&enc_l_reader);
        encoder_reader_poll(&enc_r_reader);
        state.enc_l = ENC_L_SIGN * enc_l_reader.count;
        state.enc_r = ENC_R_SIGN * enc_r_reader.count;

        if (absolute_time_diff_us(get_absolute_time(), next_tele) <= 0) {
            uint32_t tele_ts = now_ms();
            uint32_t delta_ms = tele_ts - last_tele_ts;
            int32_t delta_l = state.enc_l - last_enc_l;
            int32_t delta_r = state.enc_r - last_enc_r;

            state.rpm_l = counts_to_rpm(delta_l, delta_ms, COUNTS_PER_WHEEL_REV_L);
            state.rpm_r = counts_to_rpm(delta_r, delta_ms, COUNTS_PER_WHEEL_REV_R);

            last_tele_ts = tele_ts;
            last_enc_l = state.enc_l;
            last_enc_r = state.enc_r;

            emit_tele(&state);
            next_tele = make_timeout_time_ms(100);
        }

        apply_motor_outputs(&state);
        sleep_ms(1);
    }
}

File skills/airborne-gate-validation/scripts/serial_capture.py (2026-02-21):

#!/usr/bin/env python3
import argparse
import json
import time

import serial


def parse_args() -> argparse.Namespace:
    p = argparse.ArgumentParser(description="Capture RP2040 NDJSON serial traffic.")
    p.add_argument("--port", required=True, help="Serial port path, e.g. /dev/cu.usbmodem211301")
    p.add_argument("--baud", type=int, default=115200)
    p.add_argument("--duration", type=float, default=3.0)
    p.add_argument("--send", action="append", default=[], help="Raw JSON line to send before capture (repeatable)")
    p.add_argument("--summary", action="store_true", help="Print telemetry delta summary")
    return p.parse_args()


def main() -> int:
    args = parse_args()
    ser = serial.Serial(args.port, args.baud, timeout=0.25)
    ser.reset_input_buffer()

    for line in args.send:
        ser.write((line + "\n").encode())
        ser.flush()
        time.sleep(0.08)

    end = time.time() + args.duration
    lines = []
    tele = []

    while time.time() < end:
        raw = ser.readline()
        if not raw:
            continue
        text = raw.decode("utf-8", "replace").strip()
        if not text:
            continue
        lines.append(text)
        try:
            obj = json.loads(text)
        except Exception:
            continue
        if obj.get("type") == "tele":
            tele.append((obj.get("ts"), obj.get("enc_l"), obj.get("enc_r")))

    ser.close()

    for line in lines:
        print(line)

    if args.summary and tele:
        start = tele[0]
        endt = tele[-1]
        print("summary_samples", len(tele))
        print("summary_start", start)
        print("summary_end", endt)
        print("summary_delta_l", endt[1] - start[1])
        print("summary_delta_r", endt[2] - start[2])

    return 0


if __name__ == "__main__":
    raise SystemExit(main())

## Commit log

2026-02-21 feat: initialize airborne classic firmware and sdk skeleton
    [single-part-frame-v13.3mf, wheel-fixed-bore.3mf]
2026-02-21 feat(sdk): add pio-based quadrature encoder telemetry
2026-02-21 fix(sdk): normalize encoder sign convention in telemetry
    [main.c]
2026-02-22 feat(sdk): estimate telemetry RPM from encoder deltas
2026-02-22 feat(firmware): implement set_rpm mapping and enable sdk motor drive
2026-02-22 chore(calibration): set wheel counts-per-rev from bench trials
2026-02-22 feat(protocol): add calibration command handlers in mpy and sdk
